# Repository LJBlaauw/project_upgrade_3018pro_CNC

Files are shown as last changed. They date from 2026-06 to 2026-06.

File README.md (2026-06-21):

# project_upgrade_3018pro_CNC

Het project is gebaseerd op opensource tools:
 - Freecad (3D parametrichs CAD)
 - Prusa slicer (3D printables voor Z unit en moerhouders
 - Kicad (PCB CAD ontwerp pico CNC, firmware GRBL webbuilder)
 - librecad (2D CAD)
 - GRBLHAL (GRBL uitbreiding voor diverse 32 bit processors)

# Dit project heft de tekort komingen van de Vevor S3018 Pro Max op

 1. Niet stijf genoeg De RVS geleiders buigen door.
 2. De Aluminium plaat is niet vlak.
 3. De spindel motor heeft een te klein vermogen.
 4. De gebruikte controller heeft de in en uitgangen direct naar buiten uitgevoerd, gevoelig voor storing.
 5. Geen eindschakelaars voor rustpositie.
 6. Te lichte XYZ motoren.
 7. Ondersteunt alleen GRBL.
 8. De moeren hebben backlash bij belasting.
 9. Geen Z-probe ingang
 10. Geen mist of Flood aansluiting

# aanpassingen

 1. Maakt gebruik van aluminium profielen en lineaire rails met blokken.
 2. gebruikt een vlakke stijve kunstof basis plaat.
 3. Maakt gebruik van een borstelloze spindle motor.
 4. Alle in en uitgangen worden gebufferd.
 5. WYZ eindschakelaars worden toegevoegd.
 6. De XYZmotoren zijn door zwaardere typen vervangen.
 7. Er is een nieuwe controller pico-CNC/GRBLHAL toegevoegd (RP2040 of RP2350, 64 bit).
 8. De XYZ-moeren worden nu gesteld zodat er geen backlash meer is.
 9. Aansluiting voor een touch plate of direct met de spindle
 10. ER zijn twee solid state uitgangen die direct uit de CNC router software aangestuurd kunnen worden.

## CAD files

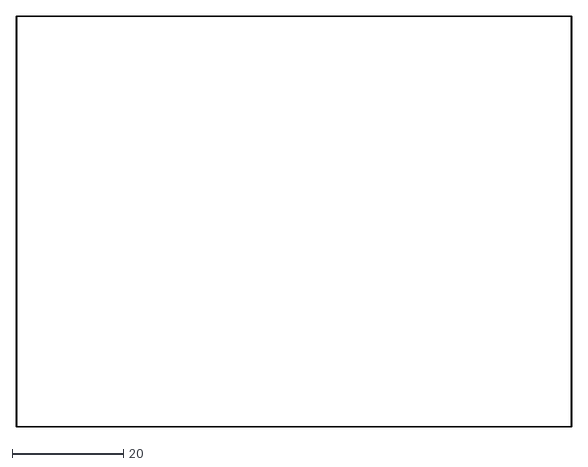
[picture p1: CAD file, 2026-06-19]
KiCAD_Pico_CNC/pico CNC-Edge_Cuts.dxf
100.1 x 74.0

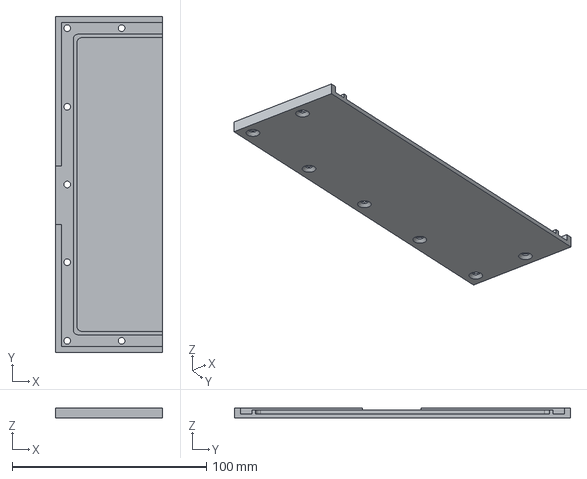
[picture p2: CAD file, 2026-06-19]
zijschut_XYU-LichaamPad002.step
55.0 x 173.0 x 5.00 mm

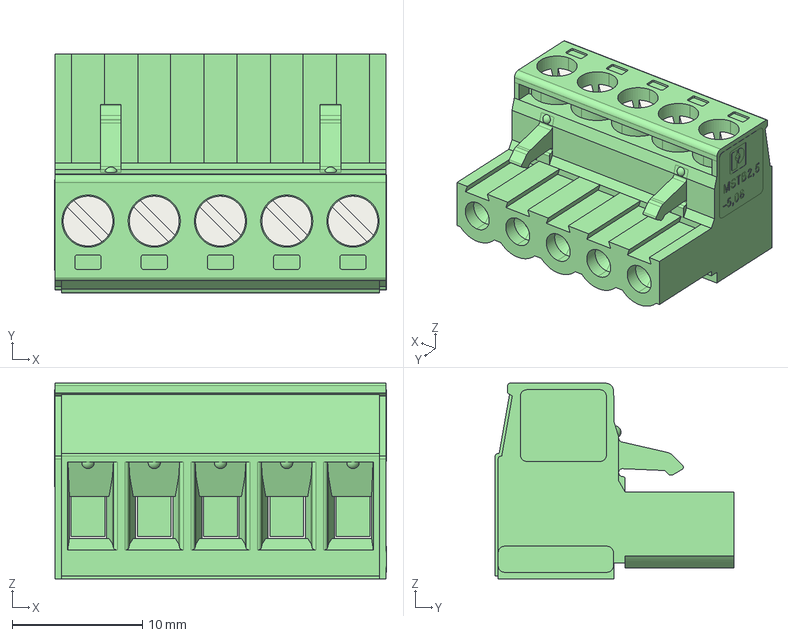
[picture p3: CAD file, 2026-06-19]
pxc_1757048_MSTB 2,5_5-ST-5,08.stp
25.5 x 18.3 x 15.0 mm

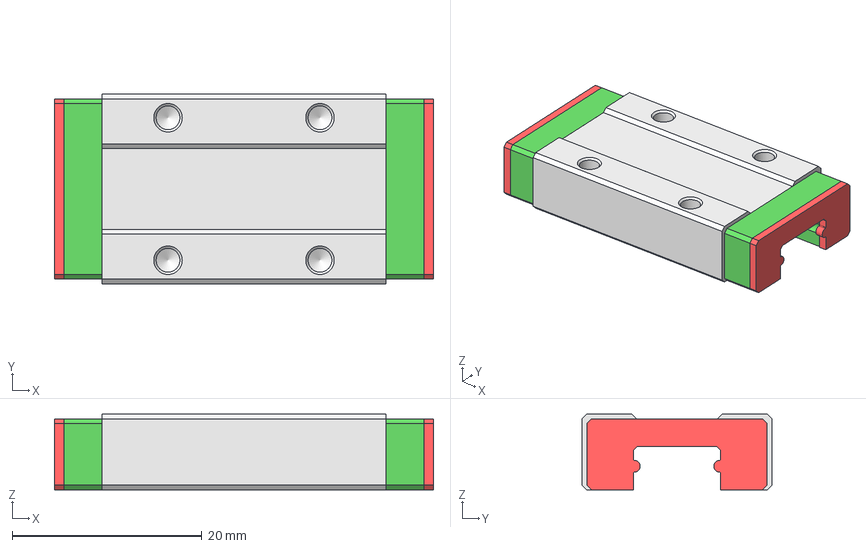
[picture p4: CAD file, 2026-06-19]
mgn9H block.step
39.9 x 20.0 x 8.00 mm
main
mid001
mid002
cap001
cap002

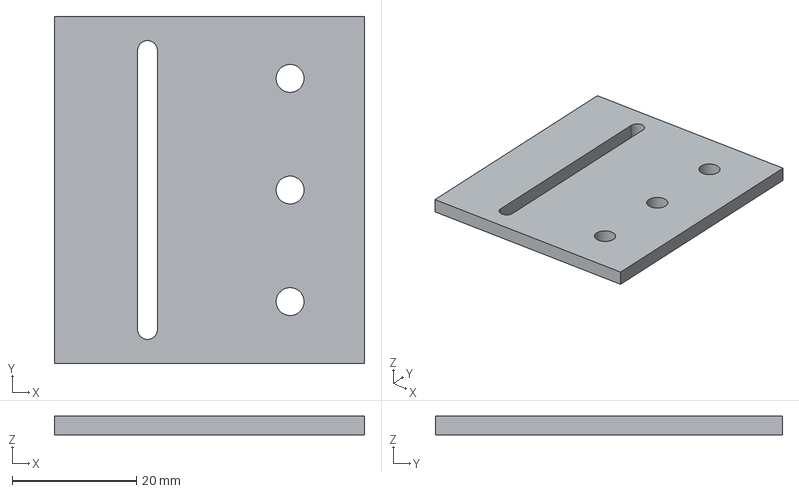
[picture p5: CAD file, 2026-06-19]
laser base plate slot.step
50.0 x 56.0 x 3.00 mm

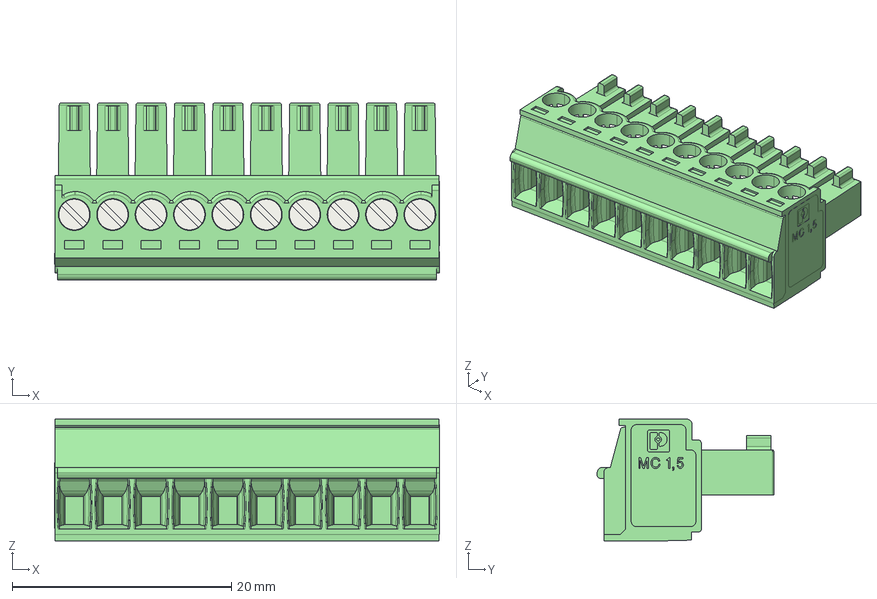
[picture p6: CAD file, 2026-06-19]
pxc_1840447_MC1,5_10-ST-3,5.stp
35.1 x 16.1 x 11.1 mm

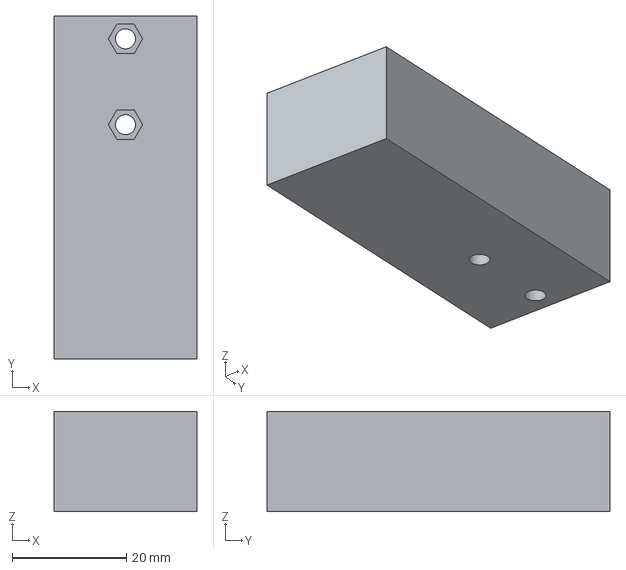
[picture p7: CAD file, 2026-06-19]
montageblok afzuigkapt.step
25.0 x 60.0 x 17.5 mm

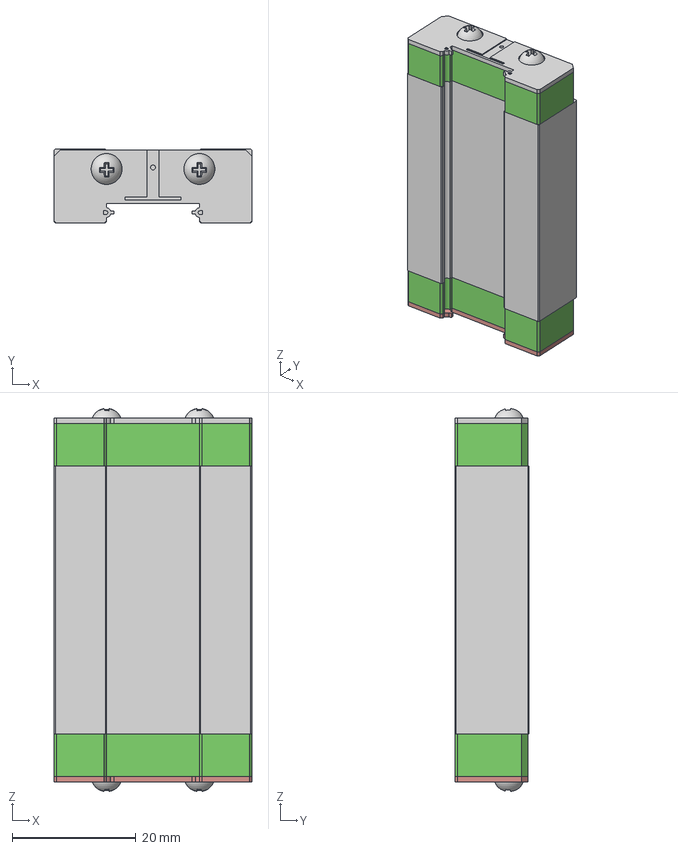
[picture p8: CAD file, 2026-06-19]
MGN15H.step
32.0 x 12.0 x 61.9 mm

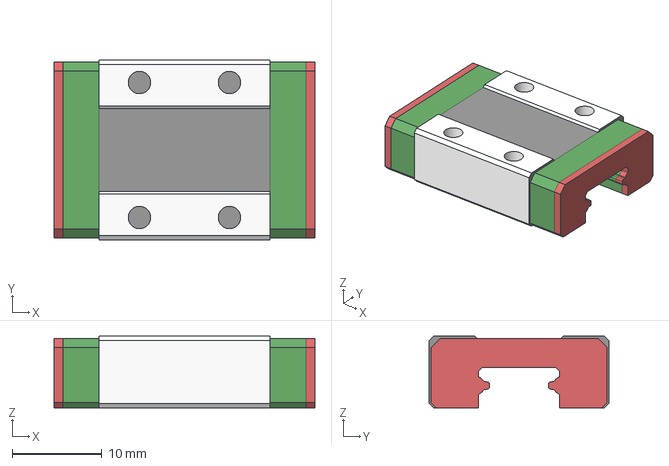
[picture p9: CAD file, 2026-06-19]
MGN9CA-MGN9CAPocket.step
29.0 x 20.0 x 8.00 mm

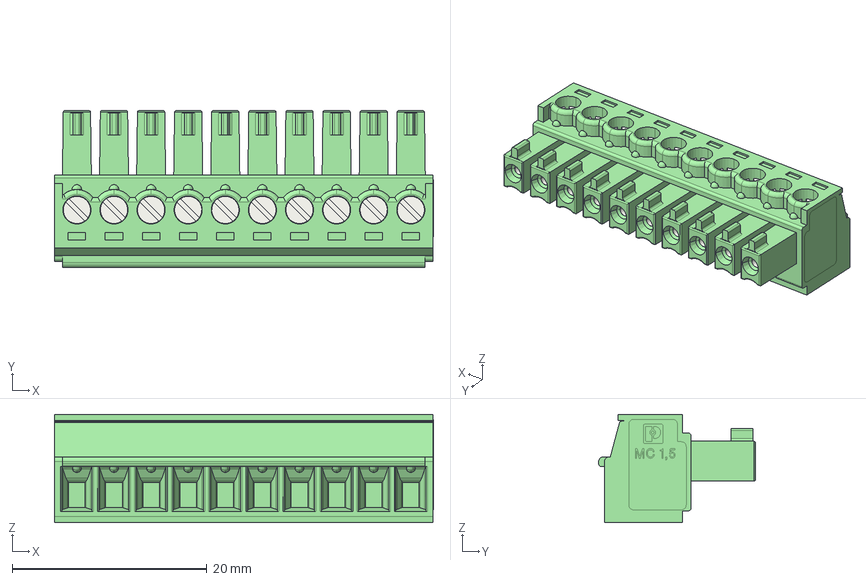
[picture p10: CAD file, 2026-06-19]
pxc_1803659 MC 1,5_10-ST-3,81.stp
38.9 x 16.1 x 11.1 mm

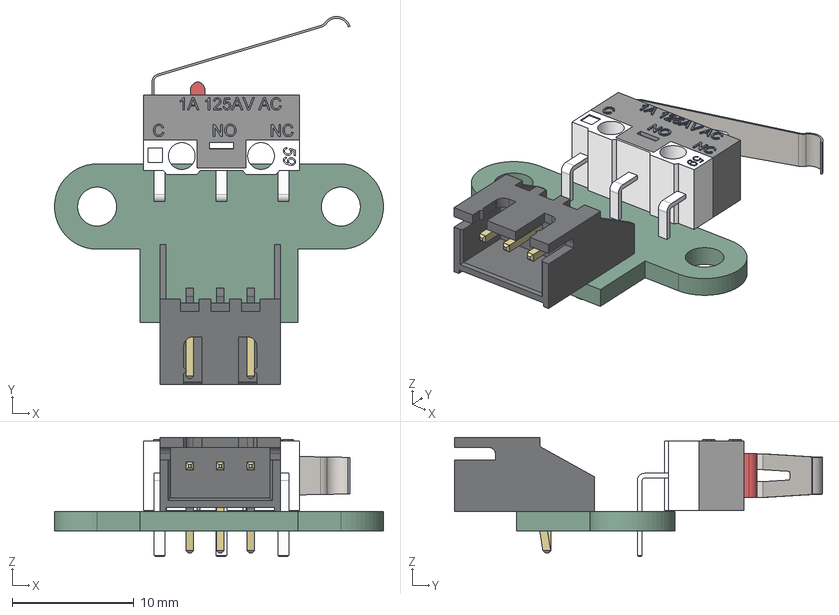
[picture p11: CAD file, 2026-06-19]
limit switch horizontal 1.step
27.0 x 30.2 x 9.80 mm
High_Part
Button
Hook_Lever
Low_Part
Low_Part001
Low_Part002
Low_Part003
pcb
JST_S3B_XH_A_1

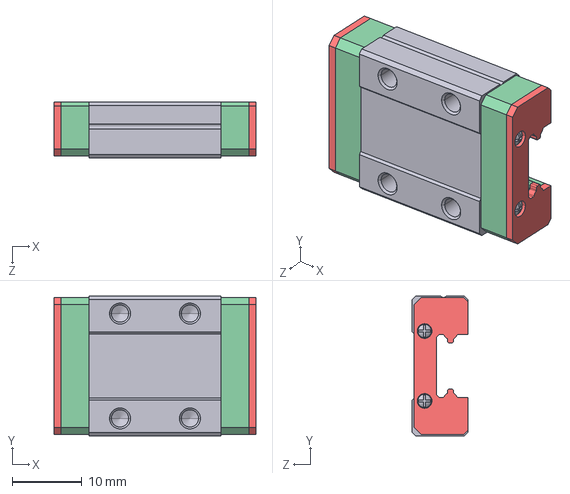
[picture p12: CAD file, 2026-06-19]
MGN9C block.STEP
28.9 x 20.0 x 8.00 mm

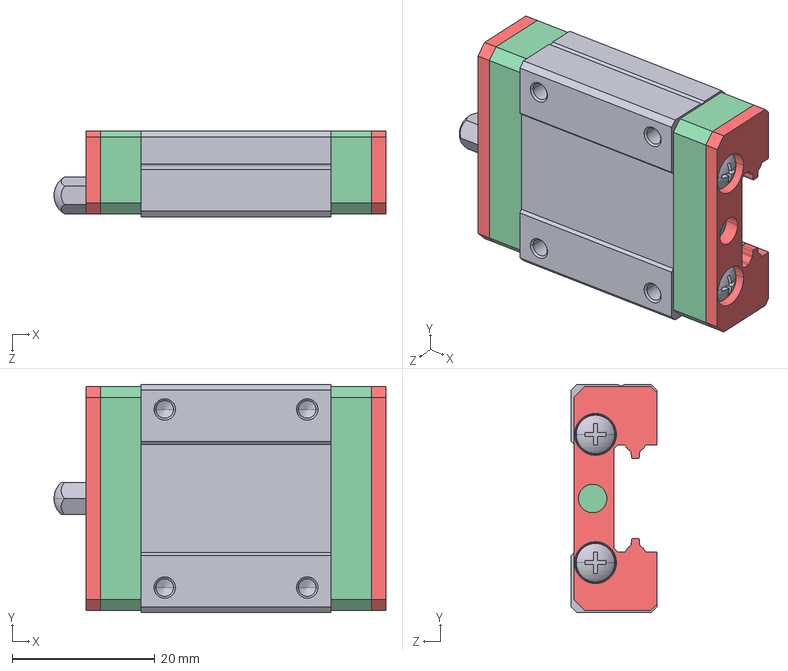
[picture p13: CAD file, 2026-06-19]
MGN15CZFC-Block.STEP
46.6 x 32.0 x 12.0 mm

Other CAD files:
assembly/Z assembly.FCStd
assembly/XZ assembly.FCStd
assembly/Y assembly.FCStd
assembly/XZY assembly.FCStd
assembly/control panel.FCStd
2020 370mm.FCStd
2040 400mm.FCStd
2040 500mm.FCStd
4040 ALU.FCStd
4040_370.FCStd
BLDC motor 300W.FCStd
Buttons panel.FCStd
Buttons panel.step
DC-DC 48-12.FCStd
ES.FCStd
HGH15CA old.FCStd
HGH15CA.FCStd
HGH15R.FCStd
HGH15R_370mm.FCStd
HGR20R 399mm.FCStd
HGW20CC old.FCStd
HGW20CC.FCStd
HKL-1D1205.FCStd
HKL-1D1212.FCStd
MGN12C.STEP
MGN12H.FCStd
MGN12R 150mm.FCStd
MGN9 rail 150 gatloos.FCStd
MGN9 rail 150.FCStd
MGN9 rail 370.FCStd
MGN9 rail.FCStd
MGN9CA new.20240802-175031.FCStd
MGN9CA old.FCStd
MGN9CA.FCStd
MGNR12 rail.FCStd
MNG15R.FCStd
Nut 8mm.FCStd
SFU1204 400mm.FCStd
TB6600.FCStd
WS55-180 BLDC driver.FCStd
XZ_U_motage profiel.FCStd
XZ_U_profile.FCStd
XZ_U_profile_switch 1.FCStd
XZ_U_profile_switch 2.FCStd
XZ_U_profile_switch.FCStd
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

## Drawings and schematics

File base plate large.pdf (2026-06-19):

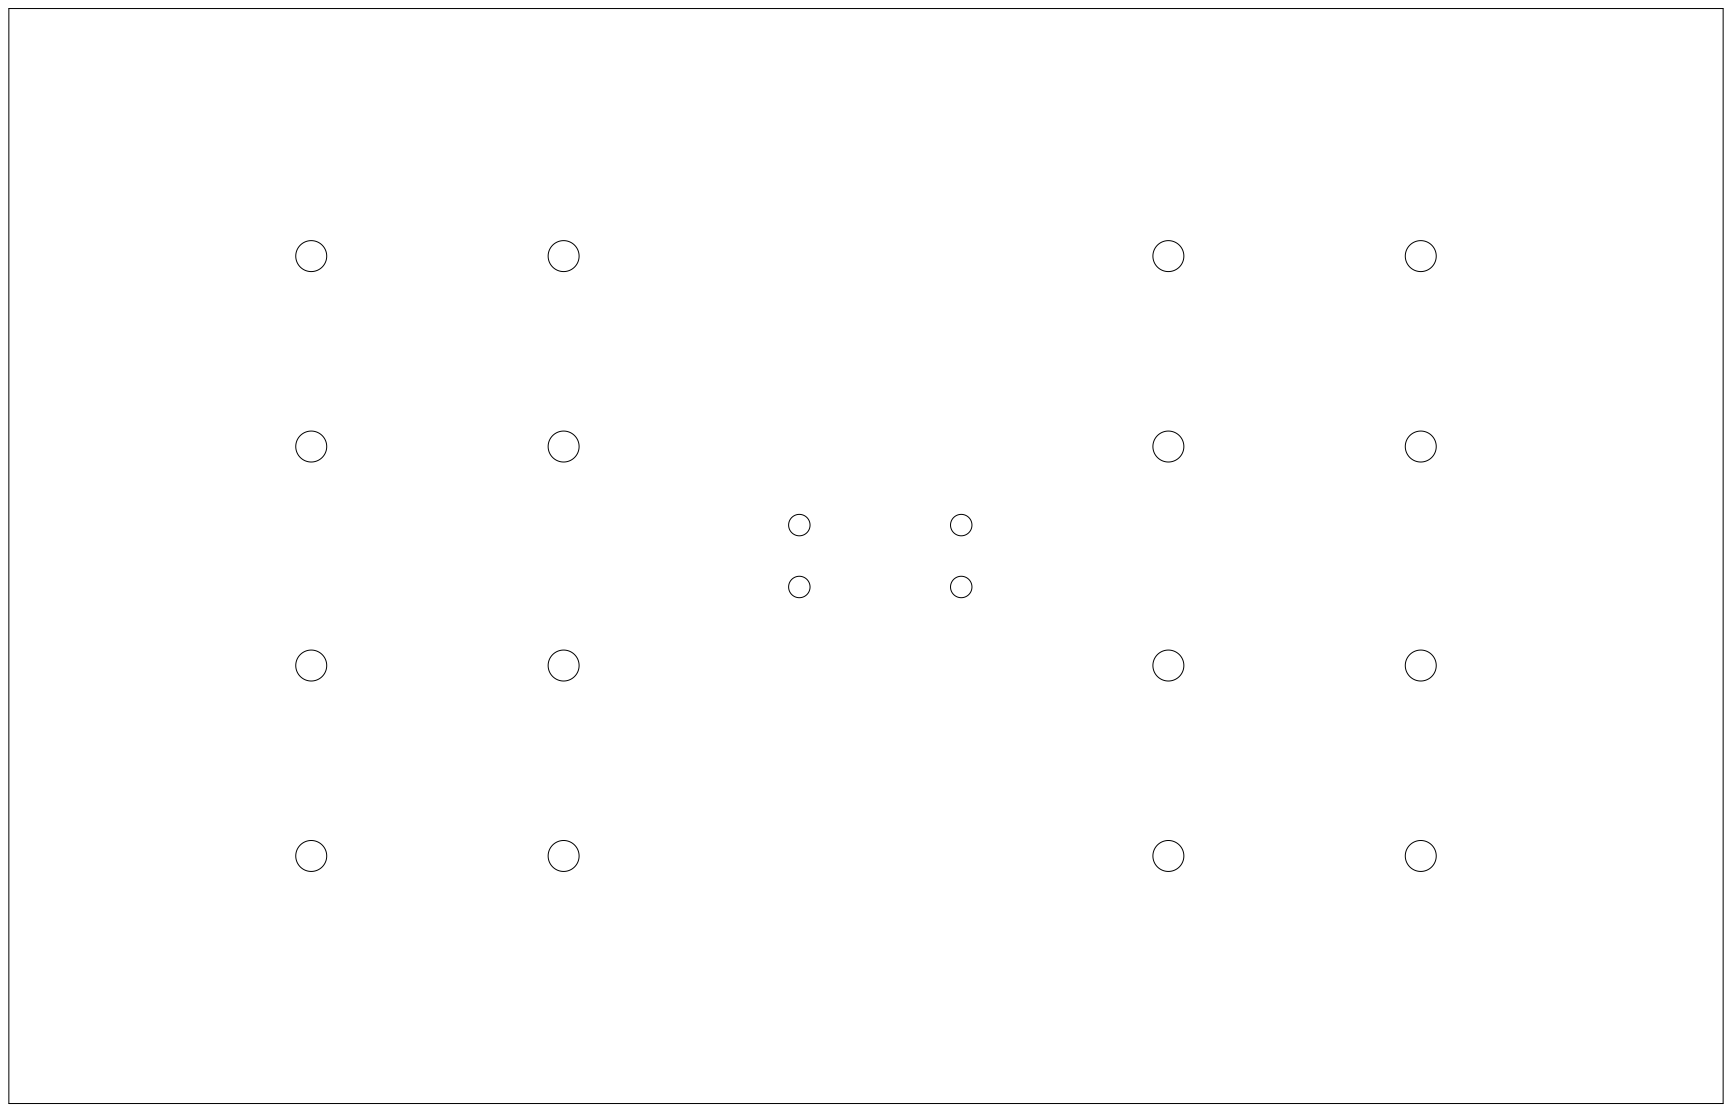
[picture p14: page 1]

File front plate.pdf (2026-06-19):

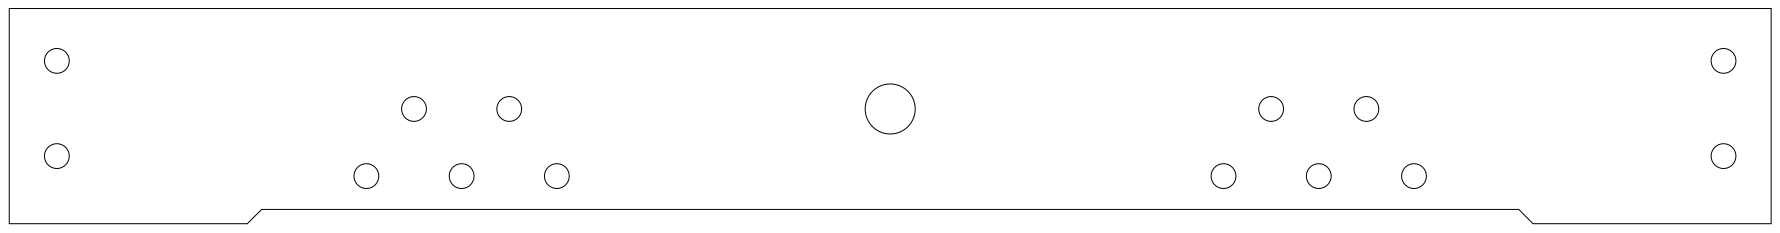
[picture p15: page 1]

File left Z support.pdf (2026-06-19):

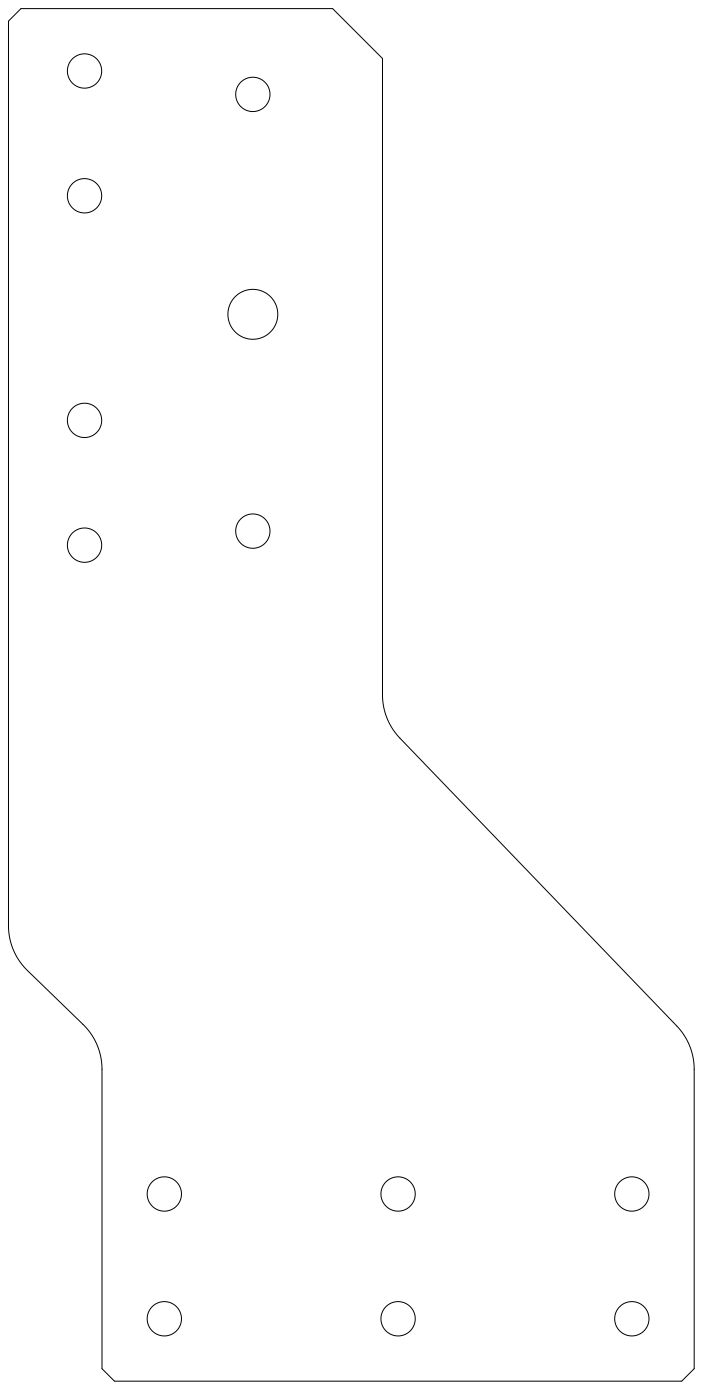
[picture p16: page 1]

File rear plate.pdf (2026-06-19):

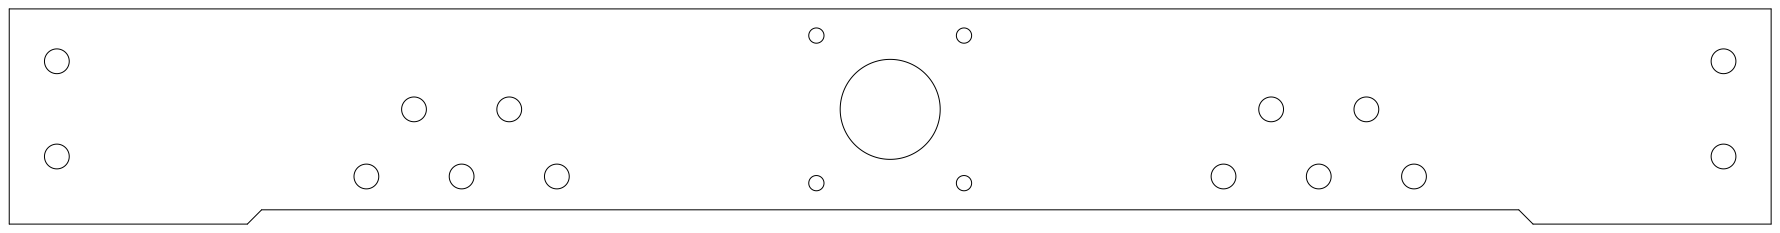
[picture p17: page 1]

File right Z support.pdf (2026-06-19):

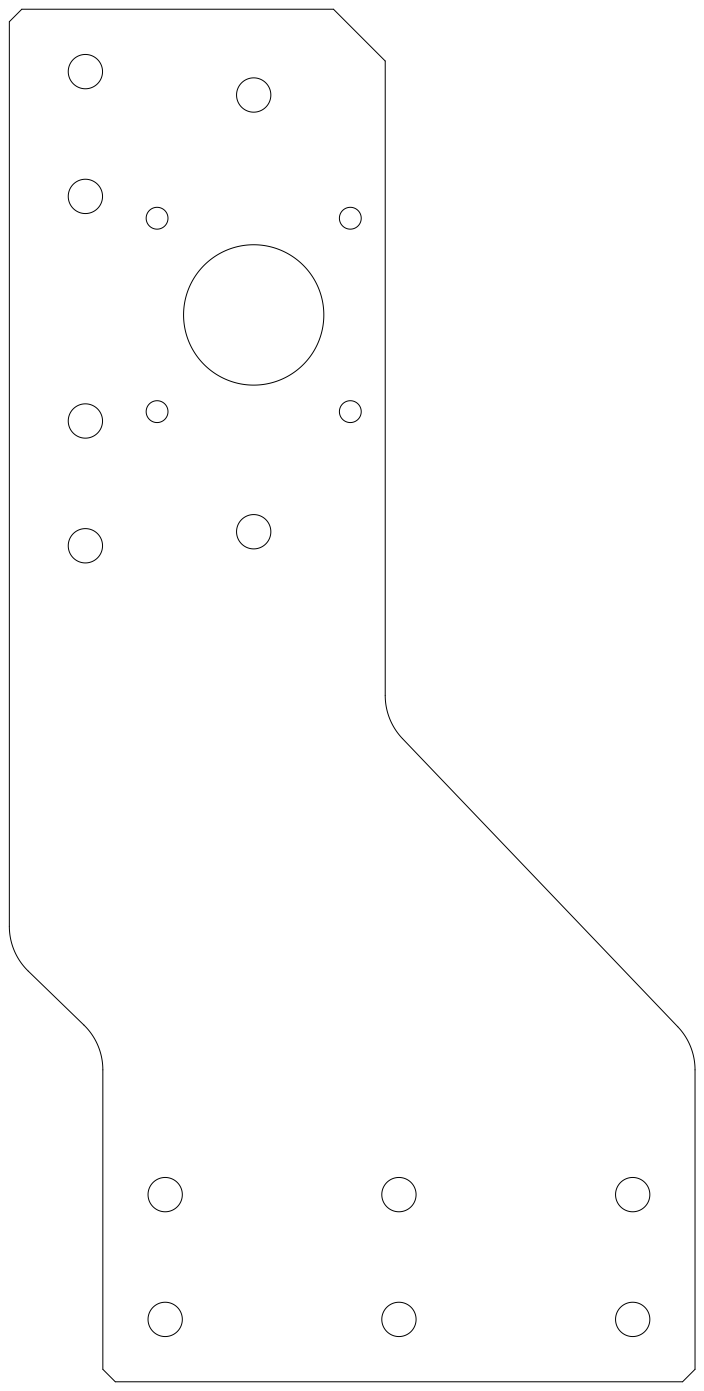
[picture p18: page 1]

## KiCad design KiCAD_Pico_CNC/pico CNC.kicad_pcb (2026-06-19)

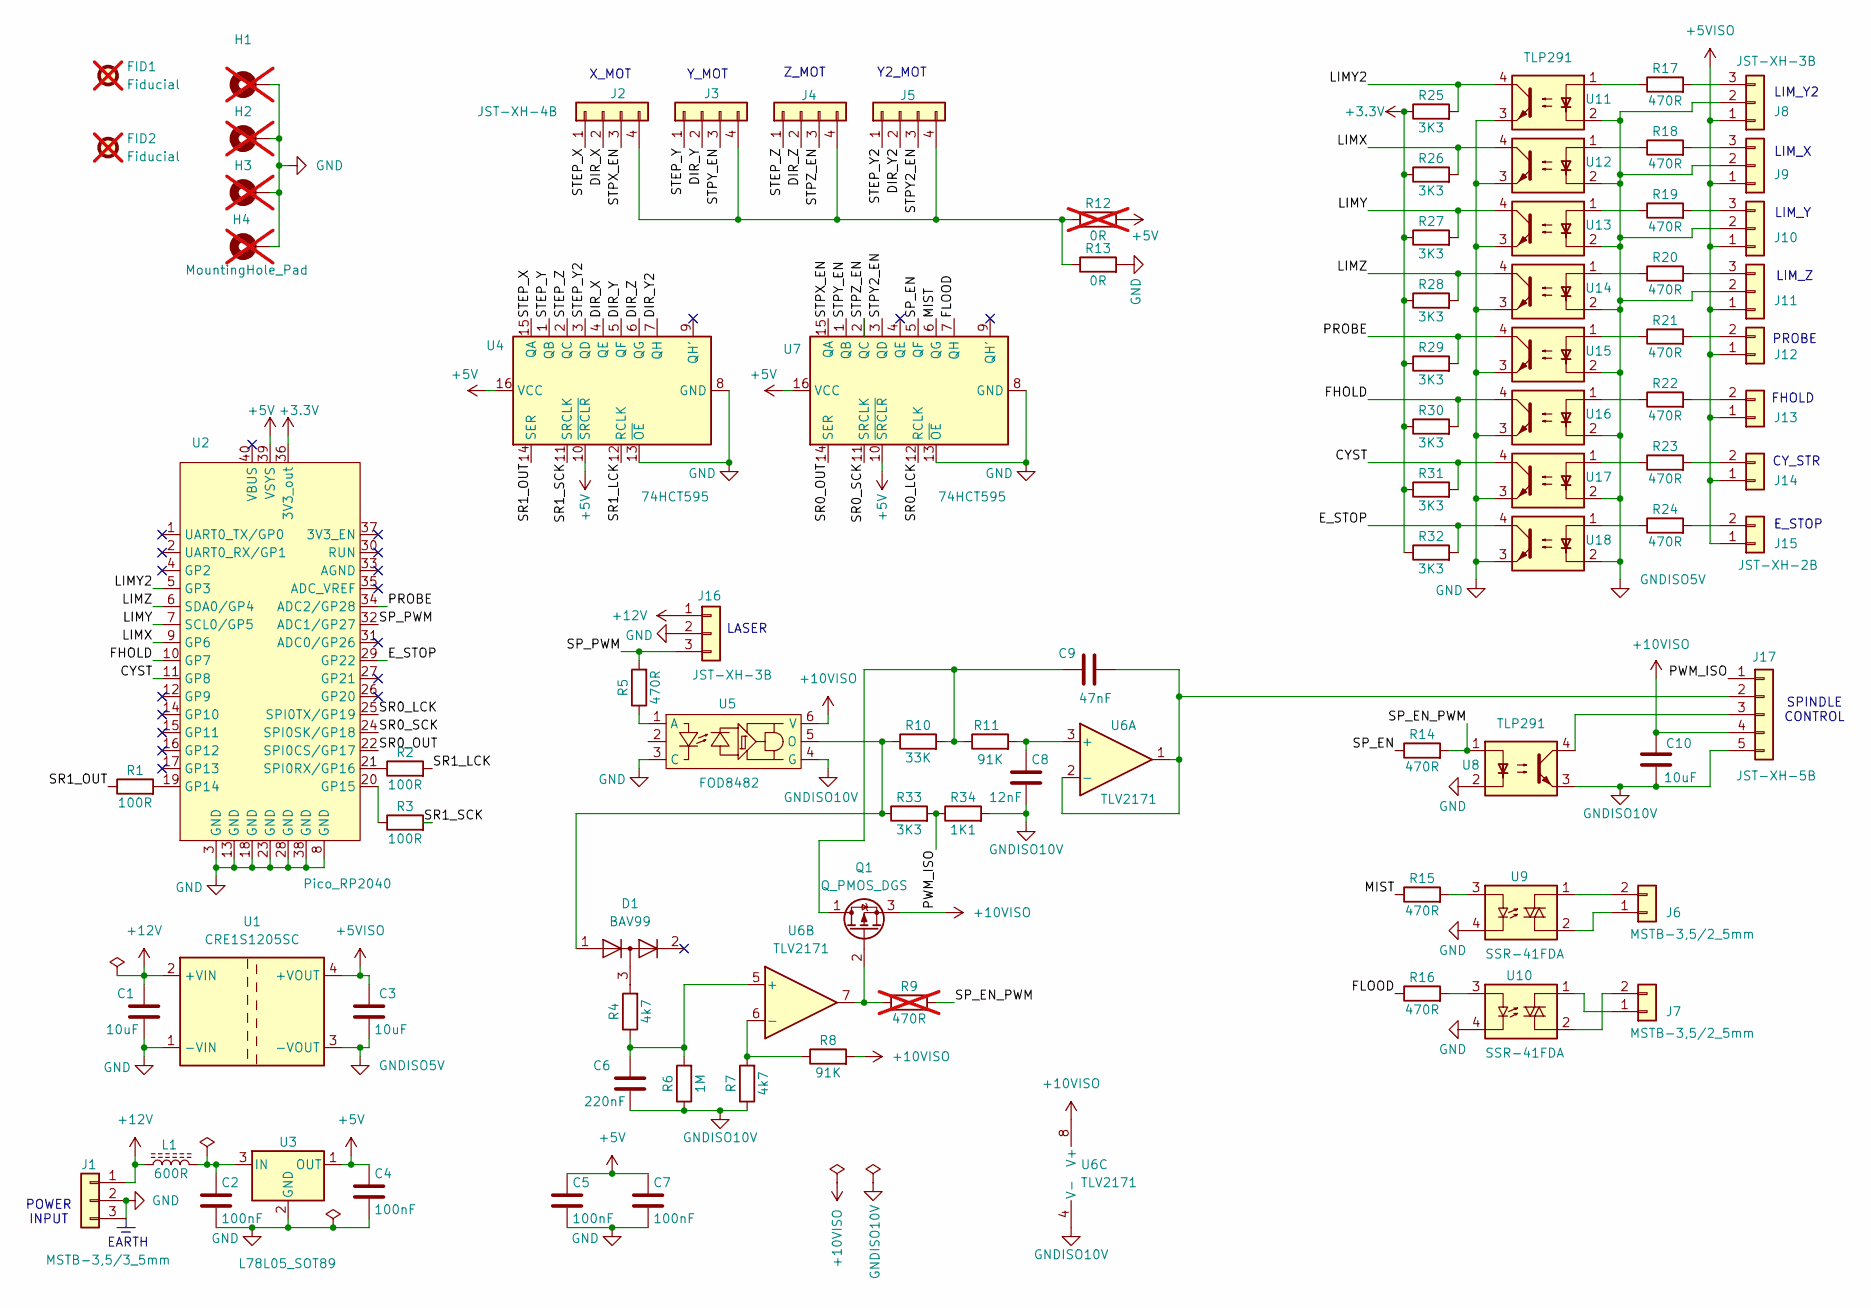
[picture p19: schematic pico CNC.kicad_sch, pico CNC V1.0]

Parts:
C1, C3, C10: 10uF; C_1206_3216Metric
C2, C4, C5, C7: 100nF; C_0805_2012Metric
C6: 220nF; C_0805_2012Metric
C8: 12nF; C_0805_2012Metric
C9: 47nF; C_0805_2012Metric
D1: BAV99; SOT-23
FID1, FID2: Fiducial; Fiducial_1mm_Mask2mm; not fitted
H1, H2, H3, H4: MountingHole_Pad; MountingHole_3.2mm_M3_Pad_Via; not fitted
J1: MSTB-3,5/3_5mm; PhoenixContact_MSTBA_2,5_3-G_1x03_P5.00mm_Horizontal
J2, J3, J4, J5: JST-XH-4B; JST_XH_B4B-XH-A_1x04_P2.50mm_Vertical
J6, J7: MSTB-3,5/2_5mm; PhoenixContact_MSTBA_2,5_2-G_1x02_P5.00mm_Horizontal
J8, J9, J10, J11, J16: JST-XH-3B; JST_XH_B3B-XH-A_1x03_P2.50mm_Vertical
J12, J13, J14, J15: JST-XH-2B; JST_XH_B2B-XH-A_1x02_P2.50mm_Vertical
J17: JST-XH-5B; JST_XH_B5B-XH-A_1x05_P2.50mm_Vertical
L1: 600R; L_0805_2012Metric
Q1: Q_PMOS_DGS
R1, R2, R3: 100R; R_0805_2012Metric
R4, R7: 4k7; R_0805_2012Metric
R5, R14, R15, R16, R17, R18, R19, R20, R21, R22, R23, R24: 470R; R_0805_2012Metric
R6: 1M; R_0805_2012Metric
R8, R11: 91K; R_0805_2012Metric
R9: 470R; R_0805_2012Metric; not fitted
R10: 33K; R_0805_2012Metric
R12: 0R; R_0805_2012Metric; not fitted
R13: 0R; R_0805_2012Metric
R25, R26, R27, R28, R29, R30, R31, R32, R33: 3K3; R_0805_2012Metric
R34: 1K1; R_0805_2012Metric
U1: CRE1S1205SC; Converter_DCDC_Murata_CRE1xxxxxxSC_THT
U2: Pico_RP2040
U3: L78L05_SOT89; SOT-89-3
U4, U7: 74HCT595; SOIC-16_3.9x9.9mm_P1.27mm
U5: FOD8482; SO-6L_10x3.84mm_P1.27mm
U6: TLV2171; SOIC-8_3.9x4.9mm_P1.27mm
U8, U11, U12, U13, U14, U15, U16, U17, U18: TLP291; TLP291 GB
U9, U10: SSR-41FDA

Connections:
+3.3V: R25.1, R26.1, R27.1, R28.1, R29.1, R30.1, R31.1, R32.1, U2.36 (3V3_out)
+5V: C4.1, C5.1, C7.1, R12.2, U2.39 (VSYS), U3.1 (OUT), U4.10 (~SRCLR), U4.16 (VCC), U7.10 (~SRCLR), U7.16 (VCC)
+5VISO: C3.1, J8.1, J9.1, J10.1, J11.1, J12.1, J13.1, J14.1, J15.1, U1.4 (+VOUT)
+10VISO: C10.1, J17.4, Q1.3 (S), R8.2, U5.6 (V), U6.8 (V+)
+12V: C1.1, J1.1, J16.1, L1.1, U1.2 (+VIN)
/CYST: R31.2, U2.11 (GP8), U17.4
/DIR_X: J2.2, U4.4 (QE)
/DIR_Y: J3.2, U4.5 (QF)
/DIR_Y2: J5.2, U4.7 (QH)
/DIR_Z: J4.2, U4.6 (QG)
/E_STOP: R32.2, U2.29 (GP22), U18.4
/FHOLD: R30.2, U2.10 (GP7), U16.4
/FLOOD: R16.1, U7.7 (QH)
/LIMX: R26.2, U2.9 (GP6), U12.4
/LIMY: R27.2, U2.7 (SCL0/GP5), U13.4
/LIMY2: R25.2, U2.5 (GP3), U11.4
/LIMZ: R28.2, U2.6 (SDA0/GP4), U14.4
/MIST: R15.1, U7.6 (QG)
/PROBE: R29.2, U2.34 (ADC2/GP28), U15.4
/PWM_ISO: J17.1, R33.2, R34.1
/SP_EN: R14.1, U7.5 (QF)
/SP_EN_PWM: R9.2, R14.2, U8.1
/SP_PWM: J16.3, R5.2, U2.32 (ADC1/GP27)
/SR0_LCK: U2.25 (SPI0TX/GP19), U7.12 (RCLK)
/SR0_OUT: U2.22 (SPI0CS/GP17), U7.14 (SER)
/SR0_SCK: U2.24 (SPI0SK/GP18), U7.11 (SRCLK)
/SR1_LCK: R2.2, U4.12 (RCLK)
/SR1_OUT: R1.1, U4.14 (SER)
/SR1_SCK: R3.2, U4.11 (SRCLK)
/STEP_X: J2.1, U4.15 (QA)
/STEP_Y: J3.1, U4.1 (QB)
/STEP_Y2: J5.1, U4.3 (QD)
/STEP_Z: J4.1, U4.2 (QC)
/STPX_EN: J2.3, U7.15 (QA)
/STPY2_EN: J5.3, U7.3 (QD)
/STPY_EN: J3.3, U7.1 (QB)
/STPZ_EN: J4.3, U7.2 (QC)
GND: C1.2, C2.2, C4.2, C5.2, C7.2, H1.1 (1_1), H2.1 (1_1), H3.1 (1_1), H4.1 (1_1), J1.2, J1.3, J16.2, R13.2, U1.1 (-VIN), U2.3 (GND), U2.8 (GND), U2.13 (GND), U2.18 (GND), U2.23 (GND), U2.28 (GND), U2.38 (GND), U3.2 (GND), U4.8 (GND), U4.13 (~OE), U5.3 (C), U7.8 (GND), U7.13 (~OE), U8.2, U9.4, U10.4, U11.3, U12.3, U13.3, U14.3, U15.3, U16.3, U17.3, U18.3
GNDISO5V: C3.2, J8.2, J9.2, J10.2, J11.2, U1.3 (-VOUT), U11.2, U12.2, U13.2, U14.2, U15.2, U16.2, U17.2, U18.2
GNDISO10V: C6.2, C8.2, C10.2, J17.5, R6.1, R7.1, R34.2, U5.4 (G), U6.4 (V-), U8.3
unnamed: D1.3 (K), R4.2
unnamed: J2.4, J3.4, J4.4, J5.4, R12.1, R13.1
unnamed: J6.1, U9.2
unnamed: J6.2, U9.1
unnamed: J7.1, U10.1
unnamed: J7.2, U10.2
unnamed: J8.3, R17.2
unnamed: J9.3, R18.2
unnamed: J10.3, R19.2
unnamed: J11.3, R20.2
unnamed: J12.2, R21.2
unnamed: J13.2, R22.2
unnamed: J14.2, R23.2
unnamed: J15.2, R24.2
unnamed: C9.2, J17.2, U6.1, U6.2 (-)
unnamed: J17.3, U8.4
unnamed: C9.1, Q1.1 (D), R10.2, R11.1
unnamed: Q1.2 (G), R9.1, U6.7
unnamed: R15.2, U9.3
unnamed: R16.2, U10.3
unnamed: R17.1, U11.1
unnamed: R18.1, U12.1
unnamed: R19.1, U13.1
unnamed: R20.1, U14.1
unnamed: R21.1, U15.1
unnamed: R22.1, U16.1
unnamed: R23.1, U17.1
unnamed: R24.1, U18.1
unnamed: R1.2, U2.19 (GP14)
unnamed: R3.1, U2.20 (GP15)
unnamed: R2.1, U2.21 (SPI0RX/GP16)
unnamed: C2.1, L1.2, U3.3 (IN)
unnamed: R5.1, U5.1 (A)
unnamed: D1.1 (K), R10.1, R33.1, U5.5 (O)
unnamed: C8.1, R11.2, U6.3 (+)
unnamed: C6.1, R4.1, R6.2, U6.5 (+)
unnamed: R7.2, R8.1, U6.6 (-)

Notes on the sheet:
Y_MOT
LASER
CY_STR
FHOLD
Z_MOT
Y2_MOT
PROBE
SPINDLE CONTROL
LIM_X
LIM_Y
LIM_Z
POWER INPUT
EARTH
E_STOP
X_MOT
LIM_Y2

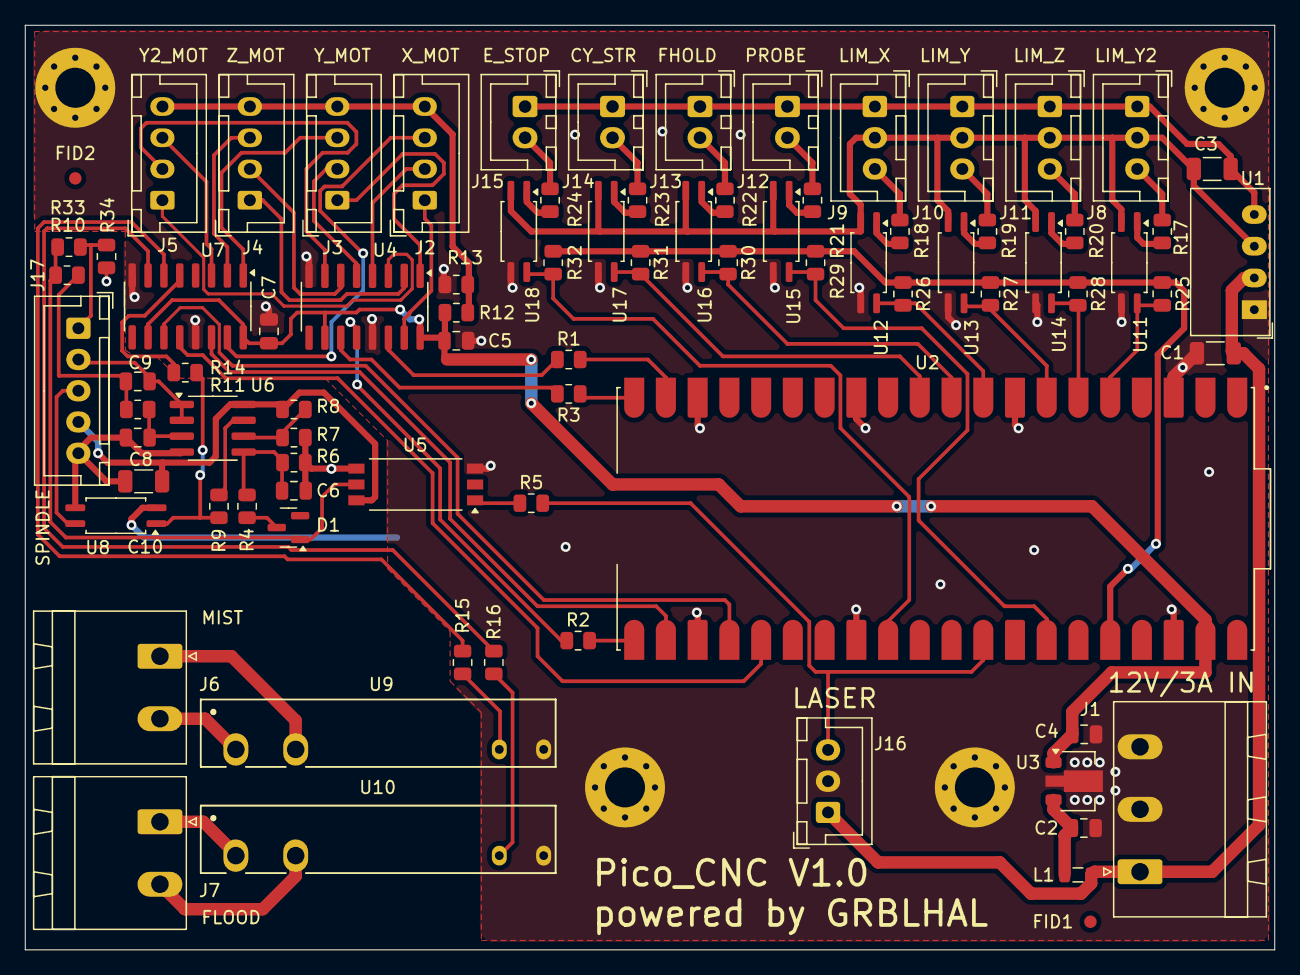
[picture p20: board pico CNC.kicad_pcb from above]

Board: 2 copper layers, 100.0 x 74.0 mm, 87 parts (0 on the bottom side), 77 nets.
